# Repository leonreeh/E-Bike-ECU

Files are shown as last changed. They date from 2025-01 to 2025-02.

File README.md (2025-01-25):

# E-Bike ECU

This repository contains the firmware and hardware design files for an Electronic Control Unit (ECU) tailored for E-Bikes. Developed as part of a technical project, it encompasses various components essential for the efficient operation and control of electric bicycles.

## Project Overview

The E-Bike ECU project aims to provide a comprehensive solution for managing and controlling the functionalities of an electric bicycle. The project includes:

- **BLDC-ESC-Firmware**: Firmware for the Brushless DC (BLDC) motor Electronic Speed Controller (ESC).
- **Gehäuse STL**: 3D printable STL files for the ECU housing.
- **LCD Case**: 3D printable STL files for the LCD display casing.
- **Motor Test Stand**: 3D printable STL files for a motor testing Setup.
- **RESC_V2 Hardware**: Hardware design files for the revised ESC version 2, Inlucding Bill of materials an Gerber files for PCB manufacturing.

## Features

- **Motor Control**: Control interface for Sensored BLDC motors up to 60V/1000W.
- **Intigrated Lighting Control**: Designed to drive 12V bike or motorcycle LEDs.

## Getting Started

To get started with this project:

1. **Clone the Repository**:
   ```bash
   git clone https://github.com/leonreeh/E-Bike-ECU.git
2. **Explore the Directories**:
Navigate to the BLDC-ESC-Firmware folder for motor control firmware.
Access the Gehäuse STL and LCD Case directories for 3D printable designs.
Refer to the Motor Test Stand folder for test stand setup 3D printable designs.
Review the RESC_V2 Hardware directory for the latest hardware schematic, layout and Bill of Material.

3. **Prerequisites Hardware**:
Sensored BLDC motor and Compatible Battery (12-60V).
3D printer for housing components.
Necessary electronic components as per the hardware design files.

4. **Software**:
STM32CubeIDE 1.16.1 or GNU Make for building the firmware.
Autodesk Fusion 360/Eagle for viewing and editing hardware schematics.
Installation
Firmware Compilation:
Navigate to the BLDC-ESC-Firmware directory.
Upload the compiled firmware to the ESC using ST-Link V2 or your preferred flashing tool.

## Acknowledgments
**Contributing**
Contributions to enhance this project are welcome. Feel free to fork the repository, make improvements, and submit pull requests.

**License**
This project is licensed under the MIT License. See the [wikipedia.org/wiki/MIT-License](https://de.wikipedia.org/wiki/MIT-Lizenz) for details.

This project was inspired and informed by several resources:

1. **VESC-Project**  Hardware reference and inspiration.
2. **Microchip** AN4064 Application Notes: Sensored (Hall Effect Sensor-Based) Field Oriented Control of Three-Phase BLDC Motor Using dsPIC33CK.
3. **Texas Instruments**
   Application Report: Trapezoidal Control of BLDC Motors Using Hall Effect Sensors.
   Demystifying BLDC motor commutation: Trap, Sine, & FOC
4. **Simple-circuits.com** Sensored brushless DC motor control.
5. **Stratify Labs** Motor Control using PWM and PID.
Special thanks to all contributors and the open-source community for their invaluable resources and Guidance.

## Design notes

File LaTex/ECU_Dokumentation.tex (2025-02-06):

\documentclass[paper=a4,11pt]{scrreprt}

\usepackage[utf8]{inputenc}
\usepackage[ngerman]{babel}
\usepackage[T1]{fontenc}	
\usepackage{amsmath}
\usepackage{graphicx}
\usepackage{listings}
\usepackage{pdfpages}

\renewcommand\lstlistingname{Source Code}
\renewcommand\lstlistlistingname{Source Code}

\usepackage{xcolor}
\definecolor{codegreen}{rgb}{0,0.6,0}
\definecolor{codegray}{rgb}{0.5,0.5,0.5}
\definecolor{codeorange}{rgb}{1,0.49,0}
\definecolor{backcolour}{rgb}{0.95,0.95,0.96}
\definecolor{funccolour}{rgb}{0.3, 0.6, 0.9}

\lstdefinestyle{mystyle}{
    backgroundcolor=\color{backcolour},   
    commentstyle=\color{codegray},
    keywordstyle=\color{codeorange},
    numberstyle=\tiny\color{codegray},
    stringstyle=\color{codegreen},
    identifierstyle =\color{funccolour},
    basicstyle=\ttfamily\footnotesize,
    breakatwhitespace=false,         
    breaklines=true,                 
    captionpos=b,                    
    keepspaces=true,                 
    numbers=left,                    
    numbersep=5pt,                  
    showspaces=false,                
    showstringspaces=false,
    showtabs=false,                  
    tabsize=2,
    xleftmargin=10pt,
}
\lstset{style=mystyle}

\title{Technikerprojekt: E-Bike ECU}
\author{Leon Reeh}
\date{\today}

\begin{document}

\maketitle
\paragraph{Vorwort}
Um das Lesen zu vereinfachen, wurde die Dokumentation in vier Teile unterteilt. Diese vier Abschnitte beschäftigen sich jeweils vollständig mit einem Aspekt des Projekts und stehen für sich:\\
\textbf{Teil 1}: Einleitung und Beschreibung des vollständigen Systems.\\ 
\textbf{Teil 2}: Dokumentation des fertigen Schaltplans, Layouts, der Software und Mechanik im Detail. \\
\textbf{Teil 3}: Der Entwicklungsprozess mit Designänderungen und deren Hintergründen.\\ 
\textbf{Teil 4}: Anhänge, einschließlich des vollständigen Schaltplans und Quellausschnitte.\\
\\Die vollständige Dokumentation sowie der vollständige und durchgehend verfügbare Software-Quellcode, Schaltpläne und weitere Dateien stehen ebenfalls in digitaler Form auf GitHub unter \textbf{https://github.com/leonreeh/E-Bike-ECU} zur Verfügung.
\paragraph{Lizenz}
Dieses Projekt und die hier beiliegende dokumentation fallen unter die MIT-Lizenz (X11-Lizenz) \emph{Leon Reeh 2025} 

\tableofcontents
\newpage

\part{Einleitung und Projektbeschreibung}
\chapter{Einleitung}
\textbf{Ziel des Projekts} ist die Entwicklung eines Steuergeräts für einen akkubetriebenen BLDC-Heckmotor mit einer Nennleistung von 1000 W bei 48 V für ein E-Bike. Das Steuergerät soll alle relevanten Bedienelemente für den Motorbetrieb sowie die Steuerung der Beleuchtung integrieren. Die Umsetzung erfolgt mit einer selbst entwickelten Platine auf Mikrocontroller-Basis und einer eigens programmierten Software.
\textbf{Motivation}
Warum habe ich dieses Projekt gewählt? 
Nach zehn Jahren Firmenzugehörigkeit bei Panasonic Lüneburg – einem Unternehmen mit Fokus auf dedizierte Elektroniklösungen – war für mich klar, dass die Entwicklung einer eigenen Elektronik im Mittelpunkt meines Techniker Projekts stehen sollte. Elektrische Antriebe sind nach wie vor ein aktuelles Thema, weshalb die Idee eines E-Bike-Antriebs nahe lag.
Warum 1kW als Herausforderung?
Mit großer Leistung kommt große Verantwortung! Da ich das Projekt privat und unter selbst gestellten Anforderungen entwickeln wollte, setzte ich bewusst auf eine hohe Leistung von 1 kW. Bei Strömen über 20 A ist die Fehlertoleranz gering. Die Bauteile müssen sorgfältig ausgewählt werden, Leiterbahnen und Kabelquerschnitte müssen korrekt dimensioniert sein, und Sicherheits- sowie Abschaltfunktionen müssen sowohl in Hardware als auch in Software sicher implementiert werden, um die Funktion und den Personenschutz zu gewährleisten.
\section{Technische Spezifikation}
\textbf{E-Bike}:\\
Reichweite: 20-40km abhängig von Fahrweise\\
Höchstgeschwindigkeit: >40km/h\\
Leistung/Ps: ~1KW/1,36PS\\
\textbf{Akku}:\\
Ausgangsspannung: 56V-43V\\
Ausgangsstrom: 30A\\
Energie: 15A/h\\
\textbf{Steuergerät}:\\
Eingangsspannung: 13V-64V\\
Stromaufnahme: standby 0.10A/ max 22 A \\
Leistungsaufnahme: 1,3W - 1.218W\\
Temperaturbereich Umgebung(Tu): 10°C - 40°C\\
Temperaturbereich Elektronik: Tu - 120°C\\

\chapter{Systemdesign}

Das fertige System besteht aus sechs Baugruppen, die über das eigens entwickelte Steuergerät vereint werden (siehe Anhang System Design \ref{EBike_sys}). Dadurch entsteht ein vollständig integriertes System, das dem Nutzer die Bedienung des E-Bikes erleichtert.
\textbf{Akku}: 48 V, 15 Ah Lithium-Ionen-Batterie
\textbf{Motor}: Viribus 26-Zoll BLDC-Heckmotor mit 1000 W Nennleistung
\textbf{Display}: 20x4 LCD-Display zur Anzeige von Geschwindigkeit und Systeminformationen
\textbf{Bedienelemente}: „Motorrad-Style“-Lenkerbedienung für alle Funktionen
\textbf{Beleuchtung}: Abblendlicht, Rücklicht, Bremslicht und Blinker
\textbf{Steuergerät}: Das Fokus Element der Techniker Arbeit.\\ Siehe Anhang System Design \ref{SysKomp} für eine Übersicht der relevanten System Bauteile.

\section{Funktionsbeschreibung}

\begin{figure}[ht]
\begin{center}
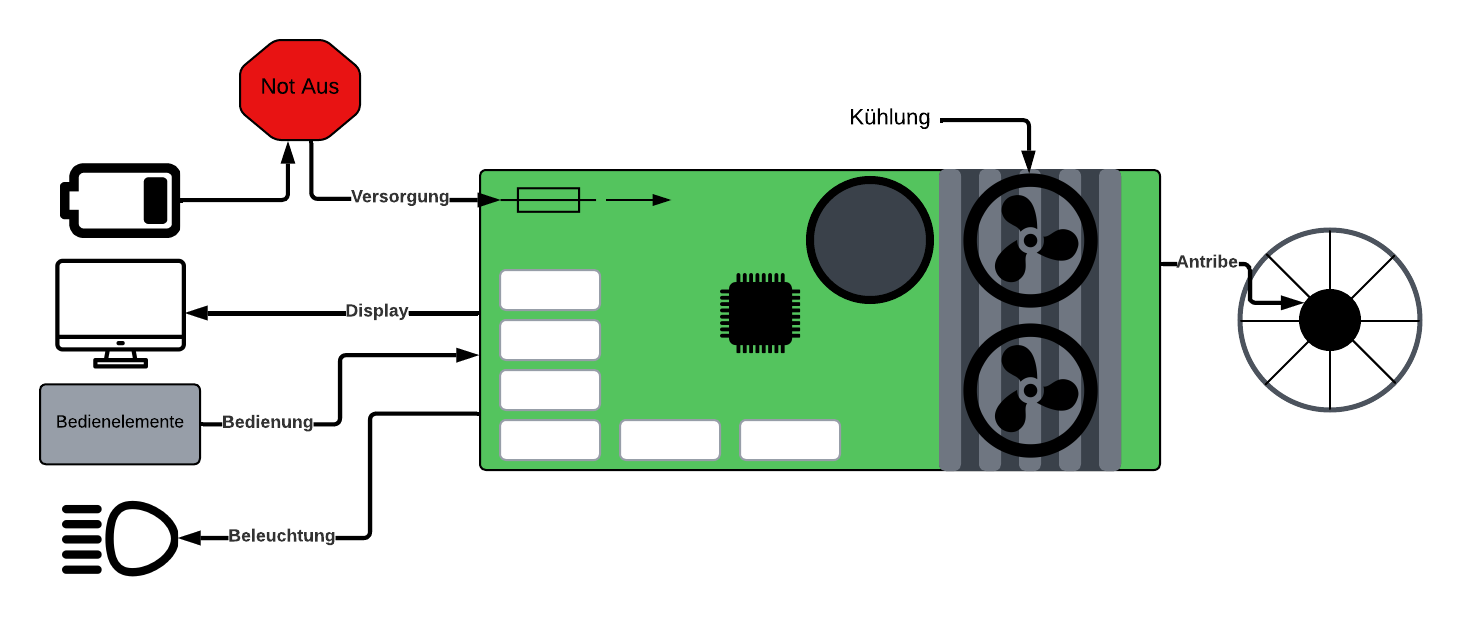
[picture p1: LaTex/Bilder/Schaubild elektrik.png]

\caption{Vereinfachtes Steuergerät}
\label{ECU_sys}
\end{center}
\end{figure}

Das Steuergerät des E-Bikes bietet folgende Hauptfunktionen:
BLDC-Heckmotor-Antrieb: 3-Phasen H brücke für den Antriebe eines bürstenlosen Gleichstrommotor (Brushless DC/BLDC).
Beleuchtungselemente:
Integrierte LED-Vorder- und Rücklichter sorgen für Sichtbarkeit und Sicherheit.
Blinkerelemente und Bremslicht für Richtungsanzeigen.
Darstellung wichtiger Betriebsdaten über LCD:
Spannung, Strom, Temperatur,Geschwindigkeit,Fehler Code.
Integrierte Temperatur-Überwachung mit diskreter Lüfter Ansteuerung.

\section{Bedienung}

\begin{figure}[ht]
\begin{center}
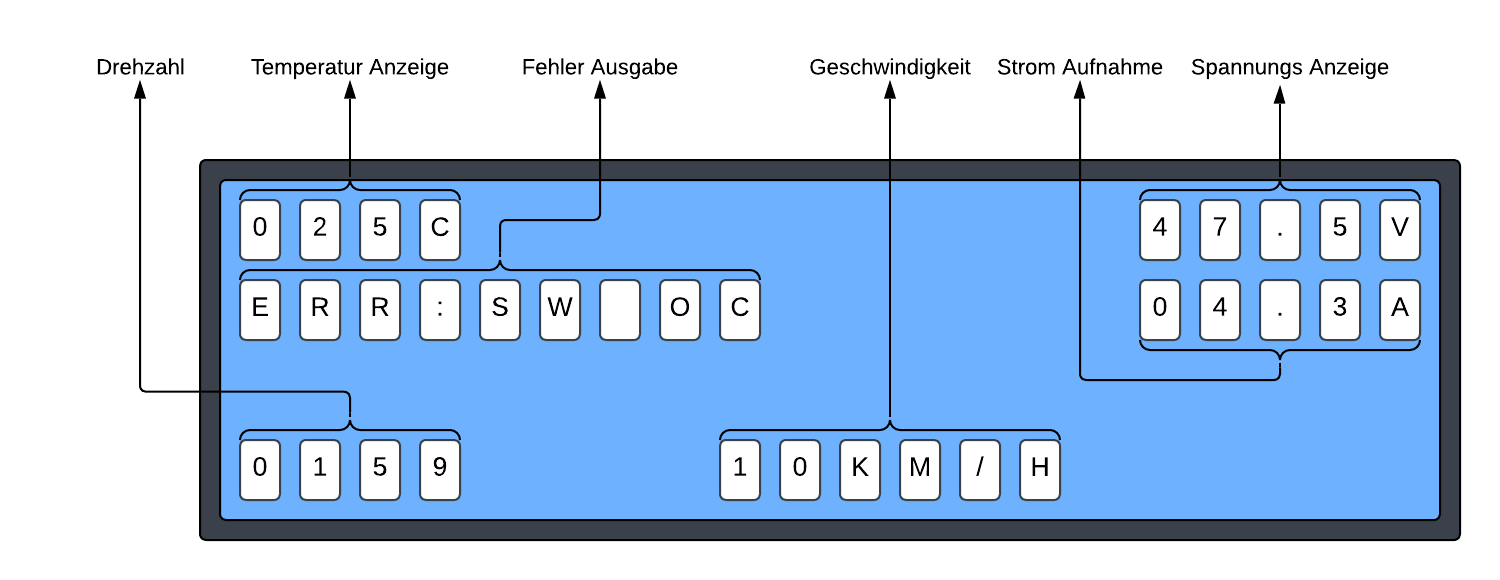
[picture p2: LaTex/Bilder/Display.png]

\caption{Display Ausgabe}
\label{display}
\end{center}
\end{figure}

Die verschiedene Bedienelemte für den Benutzer befinden sich am Lenker in einem Motorrad ähnlichem system:
\textbf{E-Stop}: Deaktiviert das Selbsthalte-Relais und schaltet das Steuergerät aus.
\textbf{E-Start}: Aktiviert das Gerät und betätigt das Selbsthaltesystem, wodurch das E-Bike in den Betriebsmodus versetzt wird.
\textbf{Bremshebel}:
Aktiviert die Bremslichter.
Schaltet die Motorbremse am Hinterrad ein, um eine zusätzliche Verzögerung zu bieten.
\textbf{Gasgriff}: Reguliert die Motorleistung und steuert die Geschwindigkeit.
\textbf{Beleuchtung}:
\textbf{Taster Ablendlicht}: Schaltet das Ablendlicht und den Rückstrahler ein.
\textbf{Taster Blinker Links/Blinker Rechts}: Steuert die Blinkerelemente für die jeweilige Fahrtrichtung.
Diese Funktionen und Eingabemöglichkeiten stellen sicher, dass das E-Bike sowohl sicher als auch benutzerfreundlich im Betrieb ist.\\

\newpage
\section{Sicherheitsfunktionen}

\begin{figure}[ht]
\begin{center}
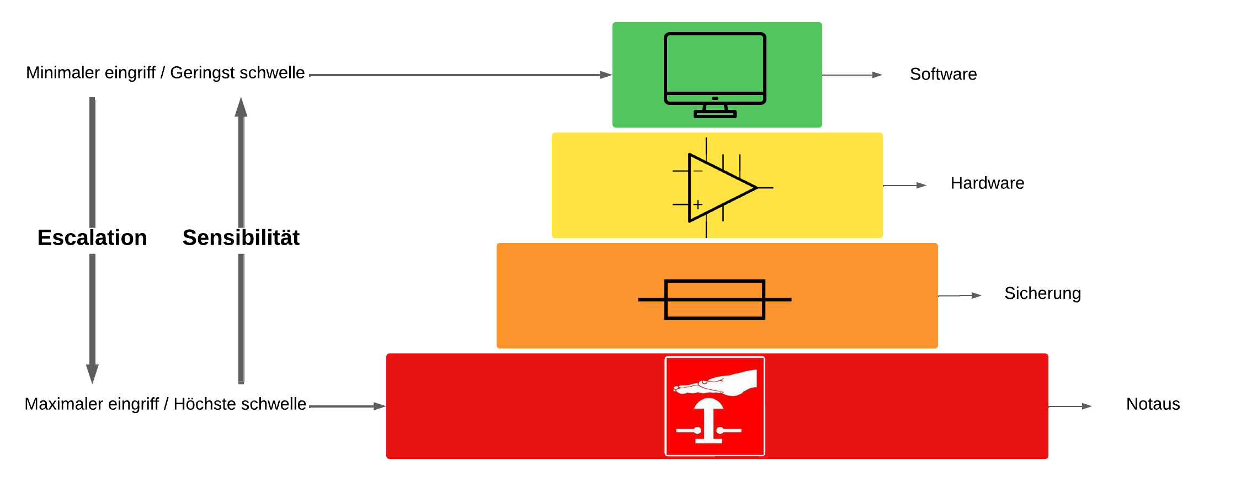
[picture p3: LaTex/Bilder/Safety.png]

\caption{Sicherheitsfunktion}
\label{safety}
\end{center}
\end{figure}

\textbf{1 Software}\\
Auslösung: Messvorrichtungen überwachen Spannung, Strom und Temperatur. Überschreiten diese Werte festgelegte Schwellen, wird der Lastbetrieb automatisch abgeschaltet.
Eingriff: Das Gerät wechselt in einen Sicherheitszustand, aus dem es sich selbstständig zurücksetzen kann, sobald die Bedingungen wieder im Normalbereich liegen.\\
\textbf{2 Hardware}\\
Auslösung: Hardwarebasierte Messvorrichtungen erkennen Spannungen, Ströme oder Temperaturen außerhalb der spezifizierten Werte und schalten das Gerät ab.
Eingriff: Das Gerät wechselt in einen Sicherheitszustand, der nur durch einen manuellen Neustart wieder verlassen werden kann.\\
\textbf{3 Sicherung}\\
Auslösung: Stromkreise für 48V (25A) und 12V (3A) sind durch Sicherungen gegen Kurzschlüsse geschützt.
Eingriff: Bei Überlast oder Kurzschluss wird das Gerät außer Betrieb gesetzt. Zum Wiederinbetriebnehmen müssen die betroffenen Stecksicherungen ersetzt werden.\\
\textbf{4 Notaus}\\
Auslösung: Im Notfall betätigt der Nutzer den Notaus-Schalter.
Eingriff: Das Gerät wird sofort vom Akku getrennt und vollständig stromlos gemacht, um maximale Sicherheit zu gewährleisten.\\
\textbf{Hinweis zu BMS-Schutzfunktionen}\\
Das im Akku integrierte Battery Management System (BMS) verfügt zusätzlich über Schutzvorrichtungen gegen Überstrom, Unterspannung und Überhitzung. Diese Funktionen sind unabhängig von den hier beschriebenen Sicherheitsmaßnahmen und waren nicht Teil der Projektarbeit. Dennoch tragen sie wesentlich zur Gesamtsicherheit des Systems bei.

\part{Schaltplan, Layout und Software}
\chapter{Schaltplan}
In diesem Abschnitt der Dokumentation werden die einzelnen Teile des Schaltplans vorgestellt und detailliert beschrieben. Der vollständige, ununterbrochene Schaltplan ist Im Anhang oder Digital auf GitHub unter: github.com/leonreeh/E-Bike-ECU $\rightarrow$ RESC\_V2 Hardware $\rightarrow$ RESC\_V2 Schematic.pdf\\
Zur besseren Übersicht und Verständlichkeit des Schaltplans wird die folgende Namensgebung für Signale verwendet:\\
\textbf{SENSE} – Signal eines analogen Ausgangs (z. B. Spannungsmessung).\\
\textbf{DI} – Digitaler Eingang (Digital-Logik-Eingang des Mikrocontrollers).\\
\textbf{DO} – Digitaler Ausgang (Digital-Logik-Ausgang des Mikrocontrollers).\\
\textbf{¯¯¯} – Invertierung (Signal arbeitet als Active Low – ausgelöst bei Pegel 0).

\subsection{Kernbauteile}

\begin{tabular}[h]{l|c|r}
\textbf{Bauteil} & \textbf{Name} & \textbf{Beschreibung} \\
\hline
Mikrocontroller & STM32F405RGT6 & 32bit ARM 1024 FLASH 192kB SRAM \\
\hline
Abwärtswandler & LMR36520 & 2,5A DC/DC Converter 4-65V\\
\hline
Brücken Treiber & IR2101S & Bootstrap Brückentreiber\\
\hline
Power Mosfet & IPB035N08N3GATMA & 80V/100A NMos\\  
\hline
Leistungs Relais & JD2912-1Z-12VDC & 12V/40A DC\\
 \hline
Akkustecker & XT90 & 500V/40A DC\\
\hline
Motorstecker & MT60 & 500V/30A DC\\
\hline
Systemstecker & JST-XH Serie & 250V/3A DC\\
\hline
\end{tabular}

\section{Netzteil}
Das Netzteil bildet das Herzstück der Energieversorgung und stellt sicher, dass alle elektronischen Komponenten des Systems mit den benötigten Spannungen und Strömen versorgt werden. Es gewährleistet einen stabilen Betrieb der Elektronik.
\textbf{Funktionalität:}\\
Selbsthalterelais für zuverlässiges Einschalten, für zusätzlichen Schutz gegen Vibrationen und erschüttern wurde hier ein KFZ Relais gewählt das eine besseres Haltemoment als herkömmliche printrelais bietet. \\
48V Hochleistungsversorgung für den Motor\\
DC/DC-Wandler (12V) für Beleuchtung und leistungs Elemente (max. 2.5A)\\
DC/DC-Wandler (5V) für Display und logik Elemente (max. 2A)\\
LDO-Regler (3.3V) für eine besonders stabile Versorgung auf Logik-Ebene.\\
\textbf{Besonderheiten:}
Messung des Eingangsstroms
Messung der Eingangsspannung
Hardwarebasierte Überstromerkennung
Hardwarebasierte Unterspannungserkennung.
\newpage

\subsection{Powertrain}

\begin{figure}[ht]
\begin{center}
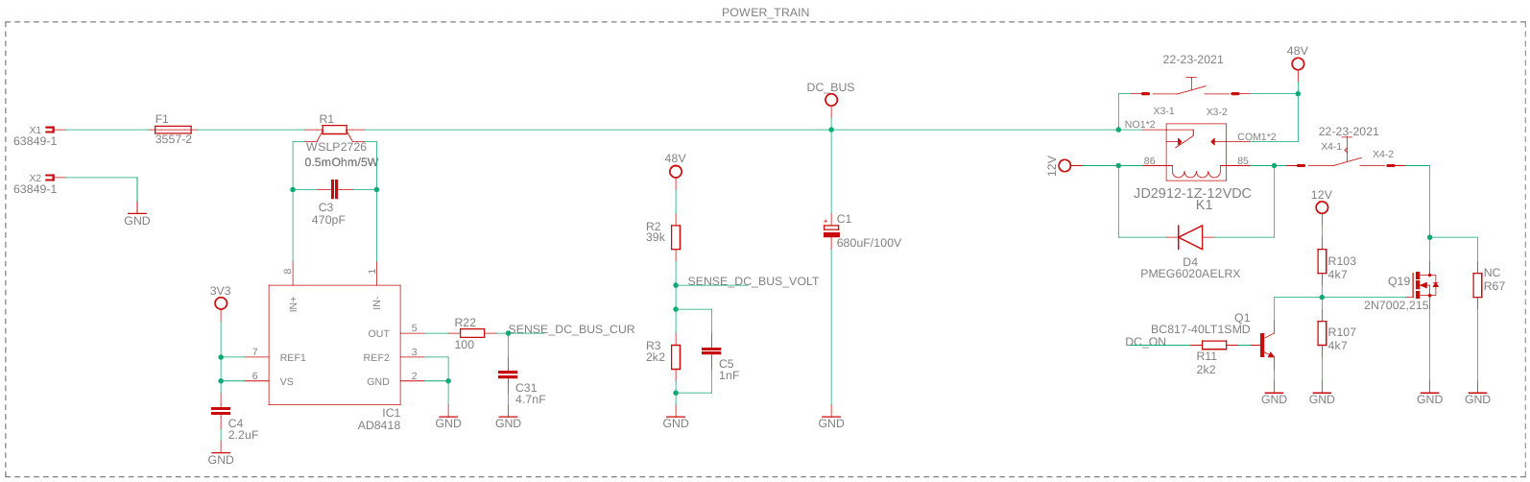
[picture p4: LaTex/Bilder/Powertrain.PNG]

\caption{RESC\_V2 Schaltplan Seite 2}
\label{Powertrain}
\end{center}
\end{figure}

In der ersten Funktionsgruppe, dem „Power Train“, sind alle Komponenten zusammengefasst, die in direkter Verbindung mit dem Akku stehen und den Hochleistungspfad für den Motortreiber bilden.
KFZ-Stecksicherung F1: Schützt den Akku vor Überstrom und Kurzschlüssen.
Shunt R1: Misst den Eingangsstrom und ermöglicht eine präzise Erfassung des Stromverbrauchs.
Spannungsteiler R2/R3: Dient zur Messung der Eingangsspannung und leitet die Daten an die Steuerung weiter.
Bulk-Kondensator C1: Glättet Spannungsspitzen und stabilisiert die Eingangsspannung, um Schwankungen auszugleichen.
Selbsthalte-KFZ-Relais K1: Schaltet die versorgungsspannung des Niederleistungspfad und sorgt dafür, dass das System sicher ein und ausgeschaltet werden kann.
Diese Funktionsgruppe ist essenziell für die sichere Versorgung des Motortreibers und bildet die Grundlage für die gesamte Energieversorgung des E-Bikes.

\subsection{DC/DC}

Um unnötige Verlustleistung zu vermeiden und die Komplexität des Netzteils gering zu halten, werden für die Versorgung der Elektronik lediglich drei Spannungsebenen benötigt:\\
\textbf{12V} – System-Leistungsspannung als Versorgung der Beleuchtung, Lüfter, Relais und des Motortreibers.\\
\textbf{5V} – Sensor- und Displayversorgung für Motor-Hall-Sensoren und des LCD-Displays.\\
\textbf{3.3V} – System-Logikspannung für die Versorgung des Mikrocontrollers, Operationsverstärkers und der analogen Signale.\\
Durch die Reduzierung auf diese drei Spannungspegel wird der Aufbau des Netzteils vereinfacht, während gleichzeitig eine stabile und effiziente Energieversorgung für die verschiedenen Baugruppen gewährleistet wird.\\
\newpage

\begin{figure}[ht]
\begin{center}
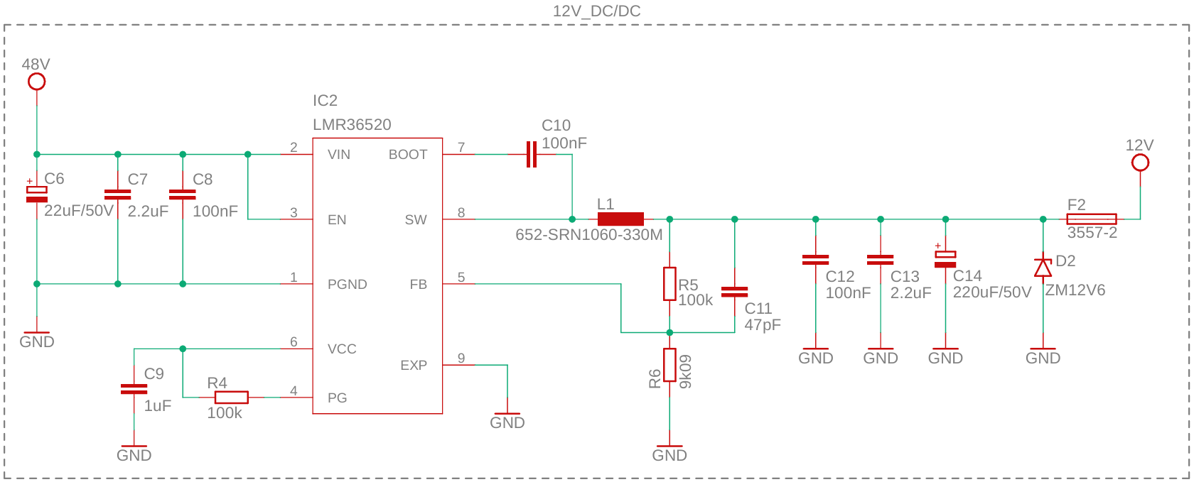
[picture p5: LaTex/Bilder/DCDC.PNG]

\caption{12V Abwärtswandler RESC\_V2 Schaltplan Seite 2}
\label{DCDC}
\end{center}
\end{figure}

Die Beschaltung des LMR36520 entspricht dem TI-Referenzdesign (Datenblatt Abschnitt 9.2 Typical Application) und wurde um eine 12V6 Suppressordiode (Z-Diode) ergänzt, um das System vor Überspannung zu schützen. Diese zusätzliche Schutzmaßnahme trägt zur Erhöhung der Zuverlässigkeit und Langlebigkeit der Spannungsversorgung bei, indem sie Spannungsspitzen effektiv absorbiert und so empfindliche Schaltungsteile schützt
Die Induktivität L1 wurde gemäß den Richtlinien im Datenblatt des LMR36520 dimensioniert (Datenblatt Abschnitt 9.2.1.2.3 – Inductor Selection).

\subsection{Protection circuits}

\begin{figure}[ht]
\begin{center}
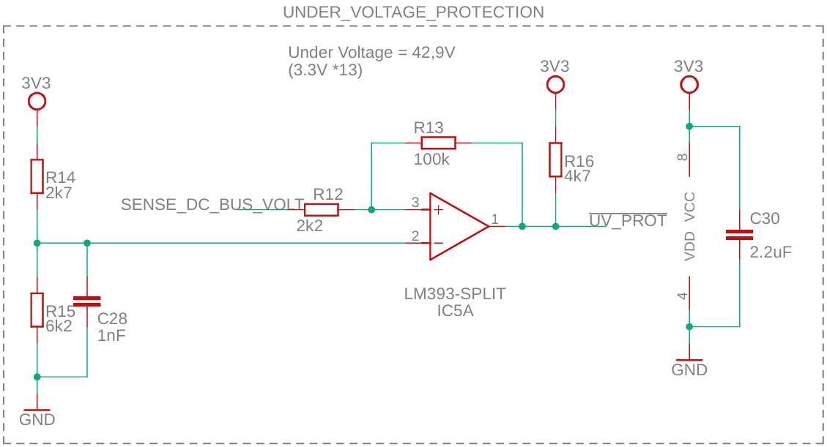
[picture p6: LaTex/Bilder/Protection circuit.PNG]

\caption{Unterspannungsschutz RESC\_V2 Schaltplan Seite 2}
\label{UV}
\end{center}
\end{figure}

Für die Umsetzung der Sicherheitsfunktion auf Hardware-Ebene wurde eine einfache Komparatorschaltung implementiert, die die drei Messgrößen (Spannung, Strom, Temperatur) überwacht. Beim Überschreiten vordefinierter Schwellenwerte sendet sie ein „Fehler“-Signal an den Mikrocontroller.
Im Beispiel in Abbildung \ref{UV} wurde zum Schutz vor Tiefentladung des Akkus eine Spannung von 42,9 V festgelegt. Bei 13 in Reihe geschalteten Zellen ergibt sich daraus eine minimale Zellenspannung von 3,3 V.
Über-Strom und -Temperatur Erkennung werden mit der gleichen Schaltung implementiert und nach relevanten Kriterien dimensioniert.

\subsection{Hardware Interrupt}

\begin{figure}[ht]
\begin{center}
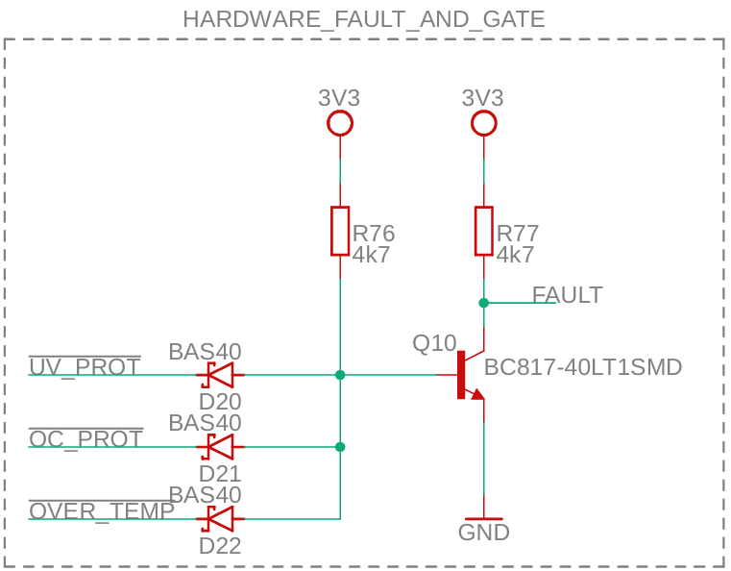
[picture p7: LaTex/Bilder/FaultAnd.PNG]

\caption{Oder Gatter RESC\_V2 Schaltplan Seite 3}
\label{orGate}
\end{center}
\end{figure}

Um sicherzustellen, dass die Elektronik im Falle eines Hardware-Fehlers immer konsistent reagiert, werden die drei Hardware-Fehlersignale (Strom, Spannung, Temperatur) über ein ODER-Gatter zusammengefasst.
Das resultierende \textbf{"FAULT"}-Signal wird auf einen Interrupt-Pin des Mikrocontrollers gelegt, sodass dieser bei einem Fehler schnellstmöglich reagieren kann. Durch diese einfache Hardwareschaltung können zwei zusätzliche Interrupt-Pins eingespart werden, da alle drei Fehlersignale zum selben Sicherheitszustand führen sollen und daher keinen eigenen Interrupt-Pin benötigen.

\subsection{Mikrocontroller}
Der STM32F405RGT6 bildet das zentrale Steuerungselement des Systems und koordiniert die gesamte Elektronik. Er übernimmt die Verarbeitung und Weiterleitung von Signalen, die Überwachung der Systemparameter, die Kommunikation mit anderen Modulen und nicht zuletzt die Ansteuerung der Motor H-Brücke.

\begin{figure}[ht]
\begin{center}
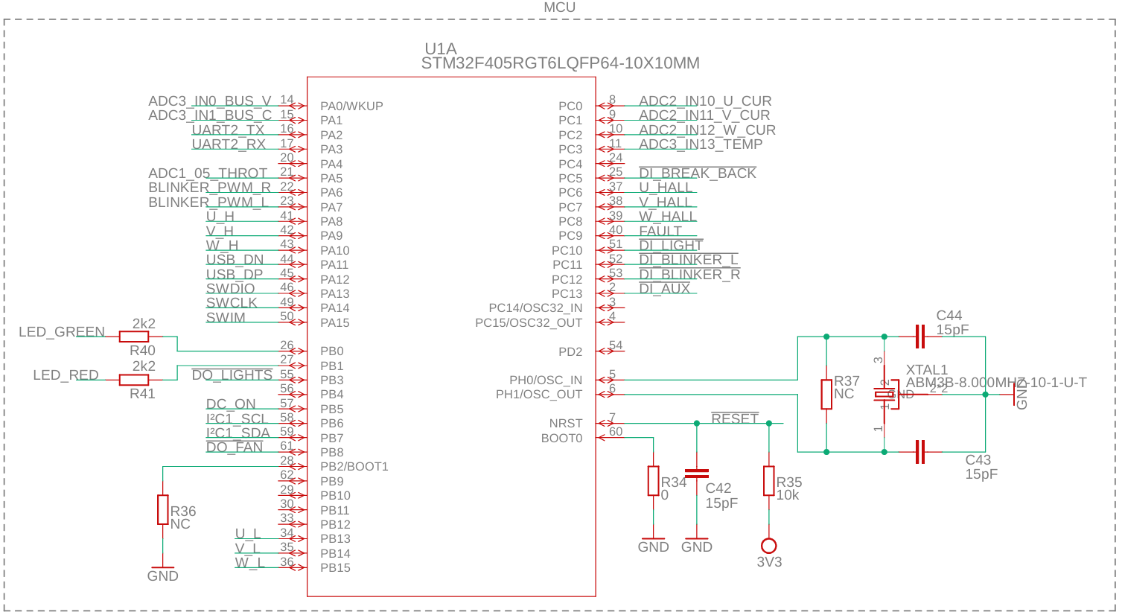
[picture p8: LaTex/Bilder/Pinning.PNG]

\caption{Mikrocontroller Pinbelegung RESC\_V2 Schaltplan Seite 3}
\label{mcu}
\end{center}
\end{figure}

Die Pin-Belegung des Mikrocontrollers wurde mit hilfe des STM32CubeIDE-Konfigurators festgelegt. Dabei wurden die Timer-PWM-Kanäle, Interrupt-Pins und ADCs konfiguriert.
Als Referenz diente der \textbf{VESC 6.4 Schaltplan}, der maßgeblich zur Auswahl des Mikrocontrollers beitrug. Diese Vorgehensweise ermöglichte die Funktions-kritisch Aspekte der notwendigen Peripheriefunktionen für die Motorsteuerung und Systemüberwachung zu implementieren.

\begin{figure}[ht]
\begin{center}
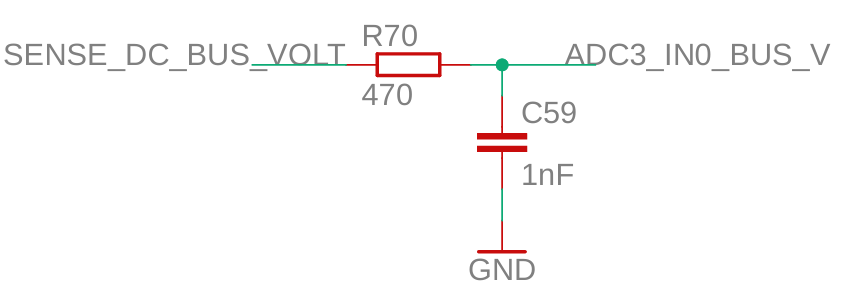
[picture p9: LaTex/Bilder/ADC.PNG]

\caption{RC-Filter RESC\_V2 Schaltplan Seite 3}
\label{ADC}
\end{center}
\end{figure}

Zur Entstörung der Analogsignale sind alle ADC-Pins des Mikrocontrollers mit einem RC-Glied ausgestattet.
Das RC-Glied dient dazu, hochfrequente Störungen zu filtern und sicherzustellen, dass die an den ADC-Eingängen gemessenen Werte stabil und präzise sind. Dies trägt zur Verbesserung der Signalqualität und zur Reduzierung von Messfehlern bei.
\newpage

\begin{figure}[ht]
\begin{center}
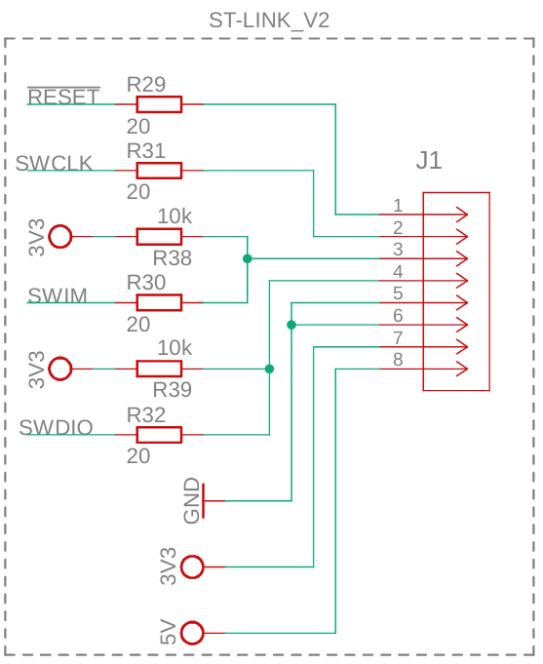
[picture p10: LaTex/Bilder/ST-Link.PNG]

\caption{ST-Link RESC\_V2 Schaltplan Seite 3}
\label{ST_LINK}
\end{center}
\end{figure}

Standard SWD-Schnittstelle zum Programmieren und Debugging von STM-Mikrocontrollern. Die Schnittstelle ist vollständig kompatibel mit dem ST-Link V2 über das Serial Wire Debug (SWD)-Protokoll.

\begin{figure}[ht]
\begin{center}
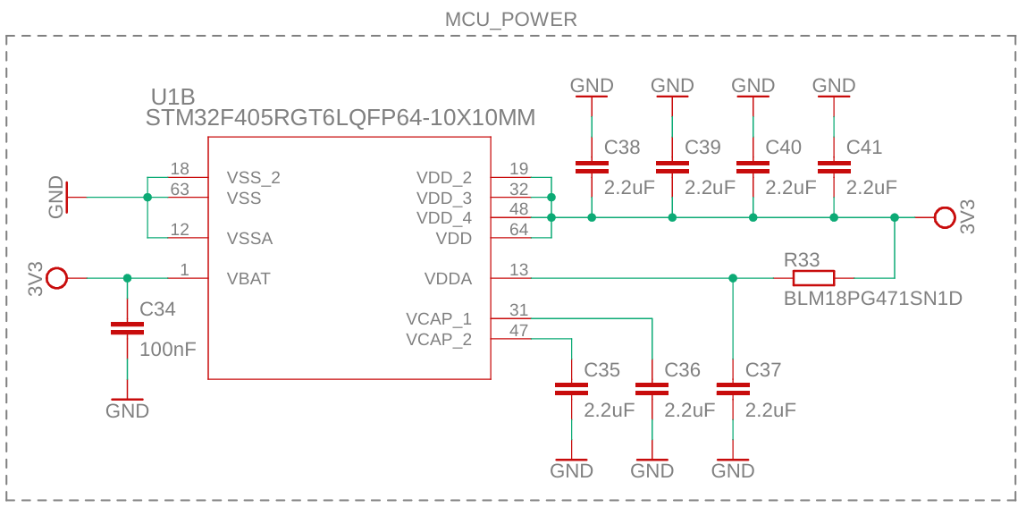
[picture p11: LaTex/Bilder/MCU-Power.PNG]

\caption{Mikrocontroller Versorgung RESC\_V2 Schaltplan Seite 3}
\label{mcu_psu}
\end{center}
\end{figure}

Jeder Versorgungspin des Mikrocontrollers ist mit einem eigenen 2,2 µF Kondensator ausgestattet, um eine möglichst stabile Spannungsversorgung zu gewährleisten. Der ADC-Referenzpin (VDDA) ist zusätzlich mit einem Ferritfilter gegen Störungen geschützt.
\newpage
\subsection{BLDC}
Für die Implementierung des BDLCs wird eine drei Phasen H-Brücke benötigt. dies wurde durch den \textbf{Infineon 2101S} Bootstrap-H-Brücken-Treiber und leistungsstarke \textbf{IPB035N08N3GATMA}-Power-MOSFETs realisiert.

\begin{figure}[ht]
\begin{center}
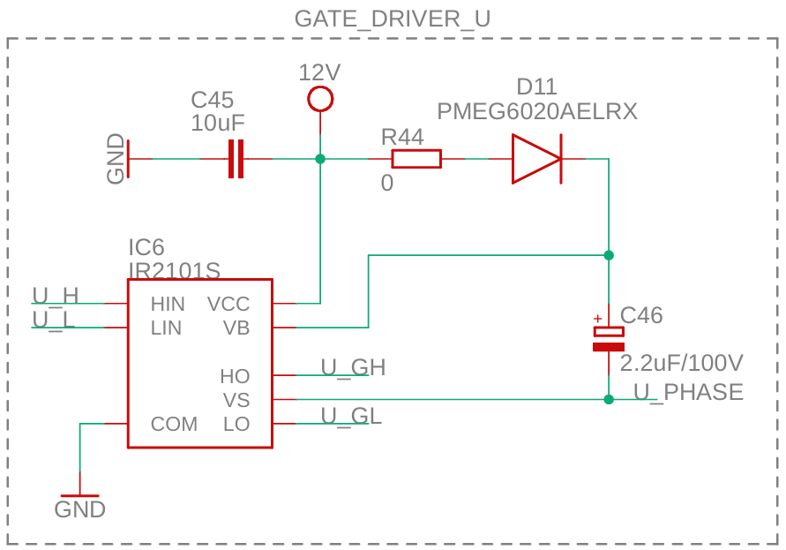
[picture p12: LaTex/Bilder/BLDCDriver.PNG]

\caption{H-Brücken Treibe RESC\_V2 Schaltplan Seite 4}
\label{GateDriver}
\end{center}
\end{figure}

Das Infineon 2101S Treiber IC wurde gewählt für seine einfache Implementierung, Ansteuerung, integrierte Bootstrap-Schaltung und Short Protection. Die Referenzschaltung wurde um einen Vorwiderstand R44 erweitert der es ermöglicht den Ladestrom von C46 zu dimensionieren. \\
Dimensionierung des Bootstrap-Kondensators C46 gemäß der Faustregel:\\ $C_{bootstrap}\geq10\times C_{gs}$ ($C_{gs}$ = 2.2nF Gate-Kapazität der MOSFETs)
Diese Dimensionierung stellt sicher, dass der Treiber auch bei hohen Schaltfrequenzen zuverlässig arbeitet und eine stabile Gate-Spannung bereitgestellt wird.
\newpage

\begin{figure}[ht]
\begin{center}
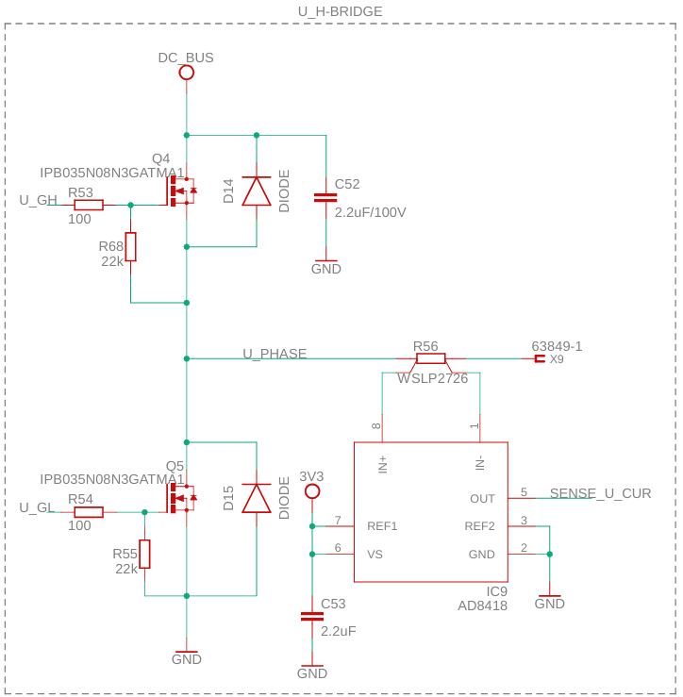
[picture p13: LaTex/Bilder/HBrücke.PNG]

\caption{H-Brück RESC\_V2 Schaltplan Seite 4}
\label{HBridge}
\end{center}
\end{figure}

Die Strom- und Drehmomentregelung erfolgt durch eine Shunt-Messung direkt am Phasenabgriff der H-Brücke, wodurch der tatsächliche Phasenstrom präzise erfasst und eine genauere Motorregelung ermöglicht wird. Zur Entlastung der MOSFET-internen Body-Dioden und zur Reduzierung der thermischen Belastung, insbesondere bei schnellen Schaltvorgängen und hohen Strömen, werden externe Freilaufdioden (D16/D17) parallel zu den MOSFETs geschaltet. Jedes MOSFET ist mit einem Pull-Down-Widerstand am Gate versehen, um ungewolltes Einschalten durch Leckströme zu verhindern und einen sicheren Sperrzustand zu gewährleisten. Zusätzlich ist jede H-Brücke mit einem 2,2 µF Kondensator ausgestattet, der Schalt- und Spannungsspitzen reduziert, die MOSFETs vor Überspannungen schützt und zur Glättung der Phasenspannung beiträgt.
\newpage
\subsection{Beleuchtung}
Die Beleuchtungseinheit steuert die LED-Beleuchtungselemente mittels diskreter MOSFET-Treibern. Ihr primärer Zweck ist die Gewährleistung der gesetzlich vorgeschriebenen sowie funktionalen Fahrzeugbeleuchtung für den Straßenverkehr, wodurch Sicherheit und Sichtbarkeit erhöht werden. Die Beleuchtung umfasst Abblendlicht, Rücklicht, Bremslicht und Blinker, wobei letztere durch Software-PWM geregelt werden, um eine flexible Lichtsteuerung zu ermöglichen.

\begin{figure}[ht]
\begin{center}
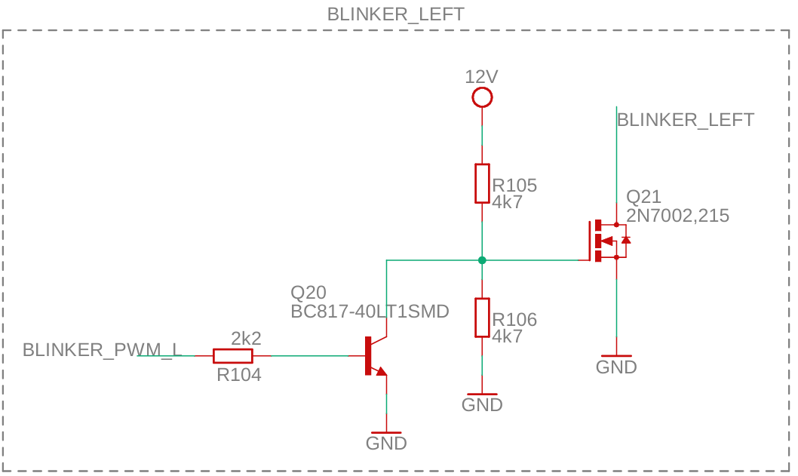
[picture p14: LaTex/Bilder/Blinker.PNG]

\caption{H-Brücken Treibe RESC\_V2 Schaltplan Seite 5}
\label{blinker}
\end{center}
\end{figure}

Alle Beleuchtungs-LEDs verwenden die gleiche Treiberbeschaltung. Der einzige Unterschied zwischen den Treibern liegt in der Größe der MOSFETs, die entsprechend der Leistungsaufnahme der jeweiligen LED-Gruppen dimensioniert werden.
\newpage
\subsection{Temperatur}
Die Temperaturüberwachung dient dem Schutz der Leistungskomponenten durch eine Messung und  Steuerung der Kühlung. Ein NTC-Sensor am Kühlkörper erfasst die Temperatur, während eine MOSFET-basierte Lüftersteuerung, mit optionalem PWM-Betrieb, eine bedarfsgerechte Kühlung ermöglicht. Eine OP-basierte Hardware-Schaltung erkennt Übertemperaturen und reagiert entsprechend, um Schäden an den Leistungskomponenten zu verhindern.
\\

\begin{figure}[ht]
\begin{center}
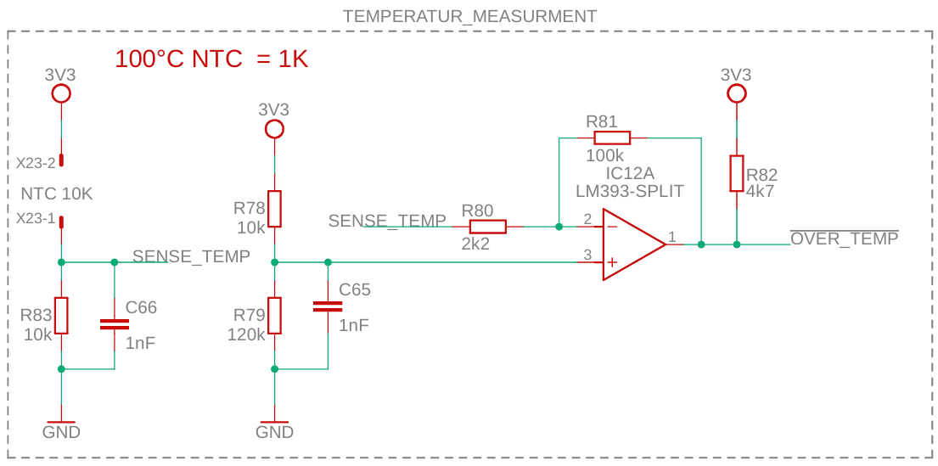
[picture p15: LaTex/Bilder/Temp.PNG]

\caption{Temperaturmessung RESC\_V2 Schaltplan Seite 6}
\label{temp}
\end{center}
\end{figure}

Der \textbf{NTC-Widerstand (R84)} ist direkt am Kühlkörper befestigt, um eine kontinuierliche Überwachung der Systemtemperatur zu gewährleisten. Die Lüftersteuerung erfolgt softwareseitig über eine \textbf{Hysterese}, wobei der Lüfter eingeschaltet wird, sobald die Temperatur \textbf{80°C} übersteigt, und wieder abgeschaltet wird, sobald sie unter \textbf{60°C} fällt. Falls die softwaregesteuerte Regelung nicht ausreicht, um den Temperaturanstieg zu begrenzen, greift eine hardwarebasierte Fehlererkennung bei \textbf{120°C} ein. Diese löst automatisch Schutzmaßnahmen aus, um die MOSFETs vor Überhitzung und möglichen Schäden zu bewahren.\\
Für das Ansteuern von zwei 40mm PC-Lüftern wird ein MOSFET-Treiber verwendet. Die Steuerung der Lüfter erfolgt über den Digital Output DO-FAN, der wahlweise im PWM-Betrieb oder im Digitalbetrieb arbeiten kann.
\newpage
\subsection{IO}
Das Eingabe- und Ausgabe-Modul ermöglicht die Interaktion zwischen Benutzer und System durch die Erfassung von Eingabeelemente wie Taster sowie die Ausgabe von Systeminformationen auf einem Kommunikationsschnittstelle. Die Kommunikationsschnittstelle kann wahlweise über eine I²C- oder UART Daten übertragen, wodurch eine flexible Integration in verschiedene Systemarchitekturen ermöglicht wird wie z.b LDC-Displays oder mehr Fortgeschrittene TFT Touch Tabletts.

\begin{figure}[ht]
\begin{center}
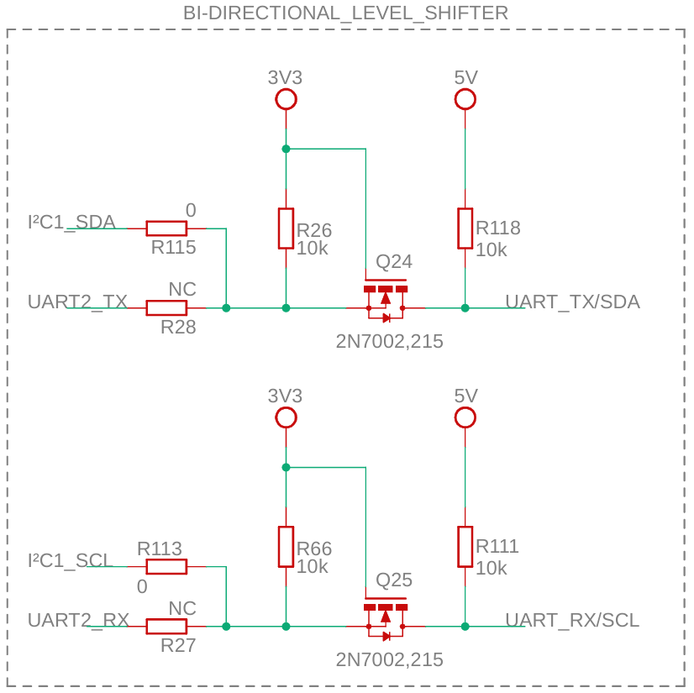
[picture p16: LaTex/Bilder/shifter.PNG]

\caption{Bidirektionaler-Levelshifter RESC\_V2 Schaltplan Seite 7}
\label{shifter}
\end{center}
\end{figure}

Die Konfigurierung der Kommunikationsschnittstelle, erfolgt über das bestücken der entsprechenden Widerstände (R28, R27 oder R115, R113). Diese Anpassungsmöglichkeit ermöglicht die Anbindung einer Vielzahl kompatibler Displays und Peripheriegeräte. Zur Sicherstellung der Kompatibilität mit Arduino-Komponenten, die auf einem 5V-Logiklevel arbeiten, ist die Schnittstelle zusätzlich mit einem Bidirektionalem 3.3V/5V-Level-Shifter ausgestattet. Dieser gewährleistet eine zuverlässige Kommunikation zwischen den Komponenten, unabhängig vom verwendeten Logikpegel.

\chapter{Layout}
In diesem Kapitel wird das Layout der Leiterplatte (PCB) detailliert beschrieben. Ziel ist es, die wichtigsten Designentscheidungen, Regelwerke und Dimensionierungen zu dokumentieren, um die optimale Funktion und Zuverlässigkeit des Systems sicherzustellen. Das angefertigte Layout finden Sie im Anhang oder digital auf: 
github.com/leonreeh/E-Bike-ECU $\Rightarrow$ RESC\_V2 Hardware $\Rightarrow$ RESC\_V2 PCB.pdf

\begin{figure}[ht]
\begin{center}
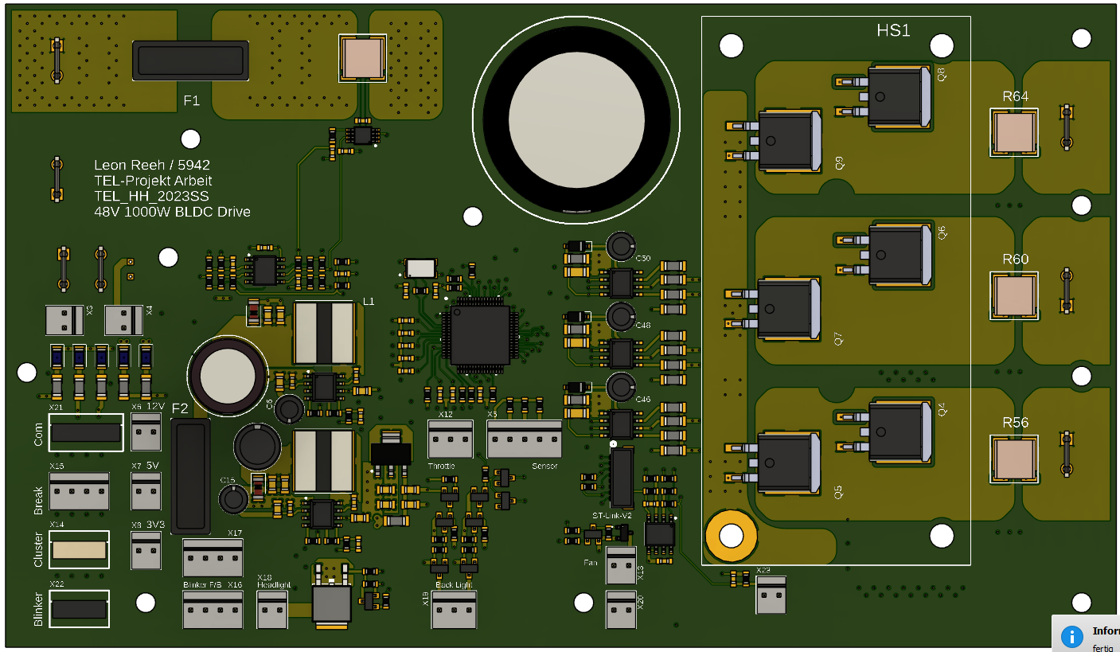
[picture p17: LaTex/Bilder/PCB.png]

\caption{RESC\_V2 Leiterplatte}
\label{pcb}
\end{center}
\end{figure}
\newpage
\section{Design Regeln}
Für die Leiterplattenentwicklung wurden folgende Design-Regeln definiert:
\textbf{Leiterbahnbreiten und -abstände:} Signal-Leitungen werden mit einer Breite von 8 mil ausgeführt, während Versorgungsleitungen im Kleinspannungsbereich ($\geq$ 12 V) 20 mil breit sind. Für Hochleistungspfade beträgt die Mindestbreite 700 mil.
\textbf{Via-Dimensionierung:} Die Vias werden gemäß den Vorgaben des PCB-Herstellers (JLCPCB) dimensioniert und besitzen eine Bohrung von 0,3 mm.
\textbf{Isolationsabstände:} Im Signalbereich beträgt der Isolationsabstand 16 mil (entspricht dem Zweifachen der Signal-Leitungsbreite), im Versorgungsnetz 20 mil und im Hochleistungsbereich 100 mil.
\textbf{Bauteilplatzierung}: Die Bauteile werden entsprechend ihren Schaltplangruppen angeordnet, sodass jede Gruppe ein schlüssiges Layout bildet. Dabei gilt die Regel: Komponenten, die zusammenarbeiten, werden auch physisch zusammen platziert. Beispielsweise werden RC-Filter (Widerstand und Kondensator) direkt nebeneinander und so nah wie möglich am zu filternden Eingang positioniert.
\textbf{Lagenaufteilung:} Der Top Layer (Layer 1) dient als Hauptbestückungslayer, während der Bottom Layer (Layer 6) als Hilfslayer genutzt wird, insbesondere für die Platzierung von Abblock-Kondensatoren nahe an den Versorgungspins des Mikrocontrollers.

\section{PCB Dimensionierung}
Die Platine besitzt eine Abmessung von 190 × 110 mm. Die einzige kritische Vorgabe bezüglich der Außenmaße war, dass sie kleiner als 210 × 210 mm bleibt, damit das PCB-Trägergehäuse auf ein 3D-Druckbett passt.\\
Die Befestigung erfolgt über mehrere M3-Schrauben, die das PCB sicher im Gehäuse fixieren. Besondere Aufmerksamkeit wurde auf die Befestigung großer und schwerer Bauteile gelegt, ebenso wie auf Bereiche, die unter mechanischer Belastung stehen, beispielsweise Stecker und Kabel. Diese Maßnahmen minimieren Biegestress und Vibrationen der Elektronik.\\
Die Design-Toleranzen richten sich nach den Fertigungsvorgaben von JLCPCB:\\
PCB-Outline: ±0,2 mm\\
Pad-Pad-Abstand: 6 mil\\
Pad-Via-Abstand: 6 mil\\
Die Steckerplatzierung wurde so gestaltet, dass eine einfache Handhabung ermöglicht wird. Stecker sind daher möglichst nah am Platinenrand positioniert, wobei die Orientierung der Platine innerhalb des Gehäuses berücksichtigt wurde. Beispielsweise sind:

Stecker für den Motor auf der Rückseite, da sich der Motor hinter der Elektronik befindet.
Stecker für Bedienelemente auf der Vorderseite, da diese leicht zugänglich sein müssen.
Eine Ausnahme bilden der Stecker für den Motor-Hall-Sensor sowie der Stecker für den Analog-Gasgriff. Diese wurden in der Nähe des Mikrocontrollers platziert, um eine optimale Signalanbindung zu gewährleisten.

\section{Layer Design}
Um unerwünschte Störeinflüsse zu minimieren und die Signalqualität zu gewährleisten, wurden die sechs zur Verfügung stehenden Layer in spezifische Signalgruppen aufgeteilt. Dies ermöglicht eine klare Trennung von Leistungs- und Signalleitungen mit dem ziel elektromagnetische Störungen (EMI) zu reduzieren. Die Verteilung der Layer folgt einem logischen Aufbau, der sich an bewährten Industriepraktiken orientiert:\\

\begin{figure}[ht]
\begin{center}
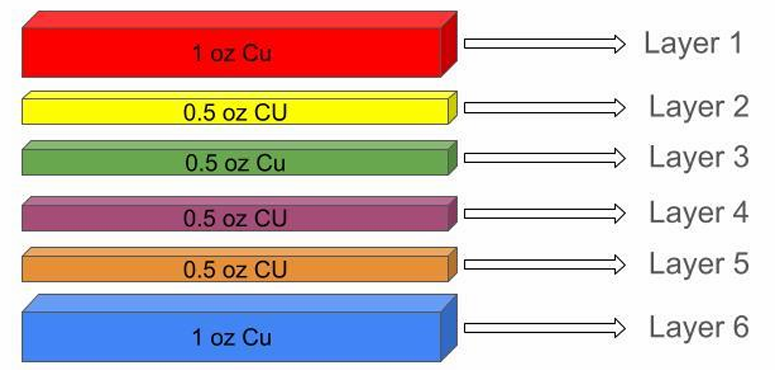
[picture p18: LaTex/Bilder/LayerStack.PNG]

\caption{6-Layer PCB Stackup RESC\_V2 Layout}
\label{lstack}
\end{center}
\end{figure}

Layer:\\
1. Baugruppen- und Power-Layer\\
2. Signal-Ground-Layer\\
3. Primär Digital-Signal-Layer\\
4. Analog-Signal-Layer\\
5. Kleinspannungs-Power-Layer (12V, 5V, 3.3V)\\
6. Primär Power-Layer\\
\textbf{Layer 1 (Top-Layer – Hochstrom und Leistungsführung):} Layer 1\&6 tragen die Hauptlast der Leistungsversorgung. Da diese Layer die dickste Kupferschicht aufweist (1 oz Kupfer pro Layer), werden sie für die Führung der 48V Versorgung und der Motorphasenströme genutzt. Leiterbahnen, die große Ströme führen, wie z. B. die H-Brücken für den BLDC-Motor, werden auf diesem Layer platziert. Breite Leiterbahnen und großzügige Kupferflächen gewährleisten einen niedrigen Widerstand und vermeiden unerwünschte Erwärmung. Der Platzbedarf für Hochstromverbindungen wird optimiert, um Spannungsabfälle und Leistungsverluste zu minimieren.\\
\textbf{Layer 2 (Signal Ground Layer):} Layer 2 dient als dedizierte Massefläche für die gesamte Leiterplatte. Diese Fläche erfüllt zwei Hauptfunktionen:
\textbf{Potentialreferenz:} Komponenten, die auf Massepotential arbeiten, können über Vias direkten Zugang zu diesem Layer erhalten, wodurch Massewege verkürzt werden und störungsfreier Betrieb gewährleistet ist.
\textbf{Schirmung:} Die großflächige Massefläche direkt unter den aktiven Komponenten dient als elektromagnetischer Schutzschild. Sie verhindert, dass hochfrequente Signale oder Störfelder von den oberflächennahen Komponenten in tiefere Layer eindringen und dort empfindliche Signale beeinträchtigen.\\
\textbf{Layer 3\&4 (Signal-Layer – Analog- und Digitalsignale):} Layer 3 und 4 sind für die Führung von Steuersignalen und Kommunikationsleitungen vorgesehen. Diese Layer wurden aufgrund ihrer Position in der Mitte des PCB-Stacks gewählt, da sie dort vor externen Störquellen am besten geschützt sind. \textbf{Layer 3 (Digital-Signale):} Hier werden digitale Steuersignale wie Kommunikationsleitungen (UART, I²C) geführt. Durch die Trennung von analogen und digitalen Signalen wird sichergestellt, dass hochfrequente Schaltimpulse die Integrität der analogen Signale nicht beeinträchtigen.
\textbf{Layer 4 (Analog-Signale):} Dieser Layer führt empfindliche analoge Signale, z. B. Spannungs- und Strommessleitungen, um sicherzustellen, dass diese möglichst störungsfrei und fern von digitalen Schaltfrequenzen verlaufen.\\
\textbf{Layer 5 (Kleinspannungs-Versorgungsebene):} Layer 5 führt großflächige Versorgungsnetze für 12V, 5V und 3.3V. Diese Spannungen versorgen Mikrocontroller, Sensoren und andere Niederspannungskomponenten. Die großzügigen Kupferflächen minimieren Spannungsabfälle und ermöglichen eine gleichmäßige Spannungsverteilung über die gesamte Platine. Vias ermöglichen es, die Spannungen direkt an die benötigten Stellen zu führen, wodurch die Anzahl langer Leiterbahnen reduziert wird.\\
\textbf{Layer 6 (Bottom-Layer – Hochstrom und Leistungsführung):} Layer 6 fungiert als ergänzende Leistungsebene zu Layer 1 und trägt ebenfalls Hochstrompfade, jedoch auf der Unterseite der Platine. Er wird für die Rückführung von Leistungsströmen und zur Anbindung an Motorphasen verwendet. Durch die symmetrische Anordnung von Layer 1 und Layer 6 wird die Strombelastung der Platine gleichmäßig verteilt und die thermische Belastung reduziert.\\
\\
Diese strukturierte Aufteilung gewährleistet eine klare Trennung von Leistungs- und Signalpfaden, reduziert EMV-Probleme und verbessert die allgemeine Zuverlässigkeit der Schaltung. Besondere Aufmerksamkeit wurde darauf gelegt, kritische Signale nicht unter Leistungsinduktivitäten oder großen Leistungstransistoren zu führen, um unerwünschte Koppelungen und Störungen zu vermeiden.\\
Die Leiterbahnbreite der Hochstromleitungen beträgt mindestens 700 mil, um Spannungsabfälle und eine übermäßige Erwärmung zu minimieren.
Der MOSFET-Heatsink ist zusätzlich mit der Power-Ground-Fläche verbunden, um die Wärmeableitung zu verbessern.
Thermisch kritische Bauteile, wie beispielsweise Schaltregler, sind mit speziellen Kupferflächen versehen.
Für eine optimale Wärmeabfuhr wurden In-Pad-Vias integriert, um die Wärme effizient von den Bauteilen zur Massefläche abzuleiten.

\chapter{Software}
Dieses Kapitel bietet eine detaillierte Beschreibung der Softwarearchitektur und geht auf die wichtigsten Module ein, die die Funktionalität des Systems gewährleisten. Von der Initialisierung der Hardware über die Motorsteuerung bis hin zur Benutzerinteraktion deckt die Software eine Vielzahl von Aufgaben ab, die in den folgenden Unterkapiteln erläutert werden.\\
Den vollständigen Quellcode zu diesem Projekt finden Sie auf GitHub unter github.com
/leonreeh/E-Bike-ECU $\Rightarrow$ BLDC-ESC-Firmware.\\
\\
\textbf{main.c/h }Board Initialisierung, Mainloop und state machine\\
\textbf{BLDC.c/h}  Interpretation des Hall Sensoren und setzen der Mosfet-Brücke\\
\textbf{liquidcrystal\_i2c.c/h} Kommunikation mit dem LCD display\\
\textbf{Mymath.c/h} mathematische Hilfsfunktionen und Berechnungen\\
\textbf{stm32f4xx\_it.c/h} Timer Interrupt-Routine, für zeitabhängige Funktionen (zb Geschwindigkeitsberechnung\\
\begin{figure}[ht]
\begin{center}
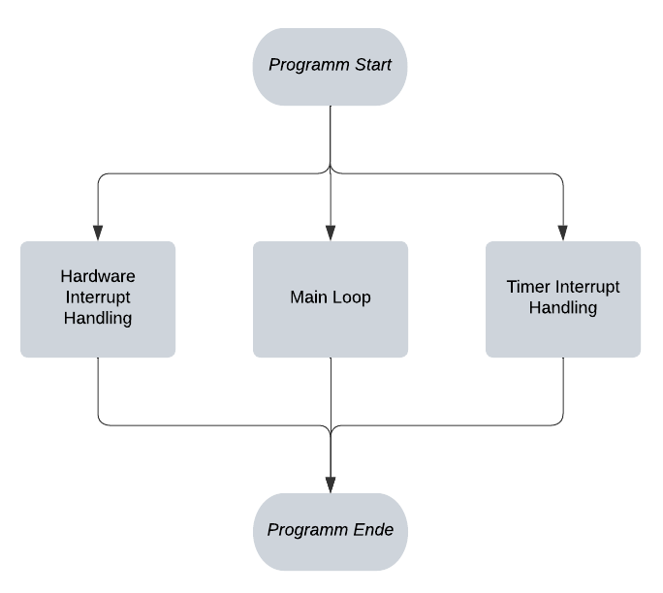
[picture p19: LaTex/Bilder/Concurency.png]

\caption{Prozess-Parallelität}
\label{concur}
\end{center}
\end{figure}
\newpage
\section{Prozesse \& Softwarearchitektur}
Das gesamte Programm wird in vereinfachter Form durch drei parallel arbeitende Prozesse gesteuert: der \textbf{Main Loop}, den \textbf{Timer Interrupt} und den \textbf{Hardware Interrupt}. Diese Prozesse übernehmen unterschiedliche Aufgaben, um eine effiziente und stabile Steuerung sicherzustellen.\\

\paragraph{\textbf{1. Der Hardware Interrupt}} wird für zeitkritische Ereignisse verwendet und reagiert unmittelbar auf bestimmte Signale. Diese Funktionen beinhalten:
Interpretation der Motor-Hall-Sensoren (Ermittlung der Motorposition)
Erkennung des Hinterrad-Bremshebels (Einleitung des Bremsvorgangs)
Verarbeitung des Hardware Fault Signals (Kritische Fehlererkennung).\\
\paragraph{\textbf{2. Der Timer Interrupt}} arbeitet mit festen Zeitintervallen und dient der periodischen Ausführung zeitgesteuerter Aufgaben. Wie der Berechnung der Drehzahl (alle 100 ms), Übertragung von Daten an das Display (alle 500 ms), Software Fault Timeout (30s).
\begin{figure}[ht]
\begin{center}
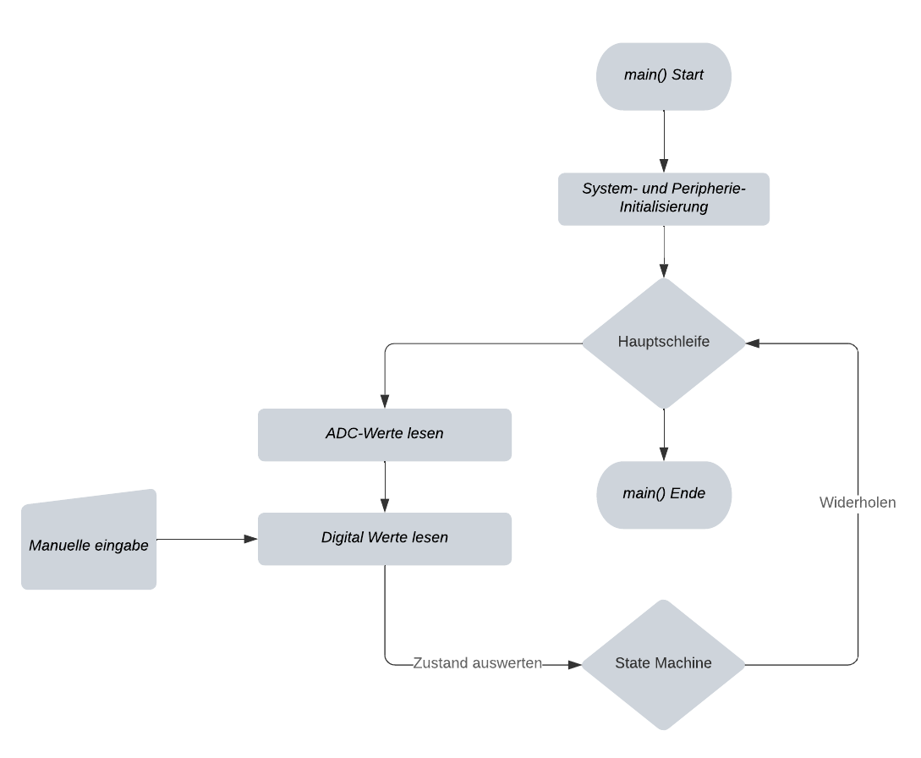
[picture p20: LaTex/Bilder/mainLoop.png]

\caption{Ablauf-Diagramm Main Loop}
\label{mainl}
\end{center}
\end{figure}
\paragraph{\textbf{3. Die Main Loop}} bearbeitet zyklisch alle nicht zeitkritischen Aufgaben.
Dies beinhaltet: Einlesen\&Konvertieren der ADC-Messwerte, Abfrage der Bedientaster, Verarbeitung der Zustandsmaschine (State Machine), Setzen der digitalen Ausgänge (z. B. Beleuchtung, Lüftersteuerung).

\subsection{Zustandsautomat/State Machine}
Um die Vielzahl der Funktionen des Mikrocontrollers effizient und sicher zu verwalten, wurde in der Main Loop ein Zustandsautomat (State Machine) implementiert. Dieses Prinzip basiert auf der Definition von klaren Zuständen und Übergängen zwischen diesen, abhängig von bestimmten Bedingungen oder Ereignissen. Ein Zustandsautomat ist ein Kontrollflussmodell, das aus folgenden Elementen besteht:\\
\textbf{Zustände:} Definieren die aktuellen Betriebsmodi oder Aufgaben des Systems (z. B. Initialisierung, Normalbetrieb, Fehlerzustand).\\
\textbf{Übergänge:} Beschreiben die Bedingungen, unter denen das System von einem Zustand in einen anderen wechseln kann.\\
\textbf{Ereignisse oder Bedingungen:} Lösen die Übergänge zwischen Zuständen aus (z. B. Sensorwerte, Timer, Benutzereingaben).\\

\begin{figure}[ht]
\begin{center}
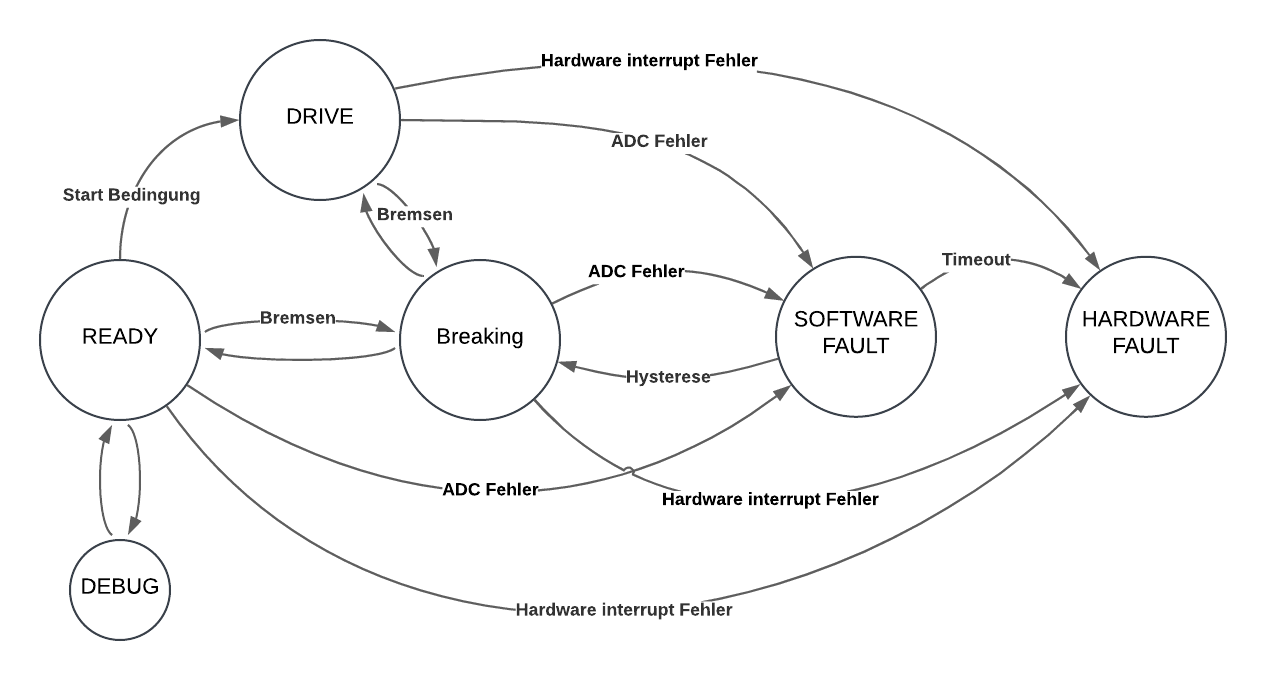
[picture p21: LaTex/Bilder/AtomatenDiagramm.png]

\caption{Zustandsautomaten Diagramm}
\label{StateM}
\end{center}
\end{figure}
\newpage

Die in Abbildung \ref{StateM} dargestellten Zustände:\\
\textbf{READY:}\\
Nach Abschluss der Systeminitialisierung wechselt der Controller in den „Standby“-Zustand.
In diesem Zustand bietet das Geräte folgende Funktionen:
Steuerung der Beleuchtung,
Initialisierung des Motors,
Aktivierung der Lüfter bei Temperaturen (T) $\geq$ 60°C.\\
\textbf{DRIVE:}\\
Dieser Zustand repräsentiert den Fahrbetrieb. Mit den Funktionen:
Steuerung der Beleuchtung,
Volle Motorleistung,
Aktivierung der Lüfter bei T $\geq$ 60°C.\\
\textbf{BRAKING:}\\
Dieser Zustand repräsentiert das aktive Motorbremsen.
Zustandsfunktionen:
Steuerung der Beleuchtung,
Motor im Bremsbetrieb,
Aktivierung der Lüfter bei T $\geq$ 60°C.\\
\textbf{SOFTWARE FAULT:}\\
In diesem Zustand wird der Motor gestoppt, Beleuchtungselemente werden deaktiviert, um Last zu reduzieren.\\
\textbf{HARDWARE FAULT:}\\
Dieser Zustand gilt als kritisch, er kann nur durch Aus- und erneutes Einschalten des Geräts verlassen werden und Blockiert alle Funktionen wie Motor und Beleuchtung-Steuerung.
Optional kann das gerät sich selbstständig abschalten durch öffnen des Selbsthalterelais.\\
\\
Übergänge wie in Abbildung \ref{StateM} dargestellte:\\
\textbf{Start:}\\
Bedingung: Das Gerät befindet sich im READY-Zustand, Drehzahl = 0,
Der Nutzer drückt den Start-Taster oder bewegt den Gas-Griff, woraufhin das Gerät in den DRIVE-Zustand wechselt und die Fahrt beginnt.\\
\textbf{Bremsen:}\\
Der Nutzer betätigt während der Fahrt den Bremshebel, wodurch ein Hardware-Interrupt ausgelöst wird.
Der Motor wechselt vom Antriebsmodus in den Bremsmodus.
Sobald der Motor bis zum Stillstand abgebremst ist, wechselt das Gerät zurück in den READY-Zustand. Wird der Bremshebel losgelassen, bevor die Drehzahl 0 erreicht, kehrt das Gerät in den DRIVE Zustand zurück.\\
\textbf{ADC-Fehler:}\\
Tritt ein ADC-Messwert über einen definierten Grenzwert (z. B. Kühlkörpertemperatur > 100°C), betritt das System den SOFTWARE FAULT-Zustand. Dieser Zustand kann nur verlassen werden in dem die Temperatur wieder unter 80°C fällt. Dies passiert über den BRAKE Zustand, um versehentliches Start des Motors zu vermeiden.\\
\textbf{Timeout:}\\
Mit dem betreten des SOFTWARE FAULT Zustands wird ein 30s Timer gestartet, wenn dieser Zustand nicht vor ablaufen dieses Timers verlässt. Wechselt es den HARDWARE FAULT-Zustand.\\
\textbf{Hardware-Interrupt-Fehler:}
Beispiel Die Spannung Des Akkus fällt unter 42.9V löst die Hardware Messschaltung (siehe Schaltplan Abbildung \ref{UV}) aus und betätigt damit den Fault Interrupt-Pin (siehe Schaltplan Abbildung \ref{orGate}). 

\section{Source Code}
Um die Dokumentation kompakt und übersichtlich zu gestalten, konzentriert sich dieser Abschnitt ausschließlich auf die Funktionen des Mikrocontrollers, die für die Hauptlogik und Steuerung des Systems entscheidend sind. Allgemeine Quellcode-Elemente wie die Konfiguration von GPIOs, Timern oder Middleware werden bewusst vernachlässigt. Die hier erklärten Source Code ausschnitte finden sie im Anhang unter Source Code
\subsection{Main.c/h}
\paragraph{\textbf{Main Loop}} siehe Anhang Source Code~\ref{main}\\
implementiert eine Endlosschleife (while(1)), die eine Zustandsmaschine zur Steuerung verschiedener Betriebszustände verwendet. In jedem Schleifendurchlauf werden zunächst Eingaben durch readADCs(), readDI() erfasst und mit doADCs() setDO() verarbeitet. Anschließend wird ein switch-Statement basierend auf der aktuellen Systemzustandsvariable (STATE) ausgeführt. Je nach Zustand (READY, DRIVE, BREAK, etc) werden entsprechende Funktionen aufgerufen, um den Systemstatus zu verwalten, beispielsweise ready(). In fehlerhaften Zuständen (SWFAULT und HWFAULT) werden die digitalen Ausgänge (DO) mit resetDO() zurückgesetzt, während in regulären Betriebszuständen setDO() aktiviert wird. Zusätzlich wird ein LCD-Display alle 500 ms aktualisiert, wenn der Zähler timcc den Wert 5 erreicht. Am Ende jedes Schleifendurchlaufs wird eine Verzögerung von 25 ms mit HAL\_Delay(25); eingefügt, um den Prozessor zu entlasten.
\paragraph{\textbf{readADCs()}} siehe Anhang Source Code~\ref{readADC}\\
Die Funktion readADCs liest analoge Werte von drei unterschiedlichen Quellen (Spannung, Strom und Temperatur) ein und speichert die Ergebnisse in einem globalen Array ADC\_VAL.
\paragraph{\textbf{doADCs()}} siehe Anhang Source Code~\ref{doADC}\\
Die Funktion doADCs analysiert die erfassten ADC-Werte, überprüft Grenzwerte und steuert Systemkomponenten wie den Lüfter basierend auf den Messwerten. Sie verwaltet zudem Zustandsübergänge und erkennt Fehlerzustände.
\paragraph{\textbf{readDI()}} siehe Anhang Source Code~\ref{readDI}\\
Die Funktion readDI liest den Zustand von vier digitalen Eingängen (Tastern) ein und aktualisiert ein globales Array but, das diese Zustände speichert.
\paragraph{\textbf{setDO()}} siehe Anhang Source Code~\ref{setDO}\\
Die Funktion setDO setzt digitale Ausgänge basierend auf dem aktuellen Zustand der Taster (gespeichert im globalen Array but) und steuert damit Systemkomponenten wie Licht, Blinker und einen Debug-Modus.
\paragraph{\textbf{ready()}} siehe Anhang Source Code~\ref{ready}\\
Die Funktion ready prüft den Gasgriff und initialisiert den Motor, falls die Startbedingungen erfüllt sind. Wenn der Gasgriff eine bestimmte Schwelle überschreitet, wird das System in den Zustand DRIVE versetzt und der BLDC-Motor gestartet.
\paragraph{\textbf{drive()}} siehe Anhang Source Code~\ref{drive}\\
Die Funktion drive liest den Gasgriffwert ein, berechnet den entsprechenden Duty-Cycle und aktualisiert diesen, um die Motorgeschwindigkeit während des Fahrmodus zu steuern. Bei einem Fehler in der ADC-Konvertierung wird der Duty-Cycle auf einen sicheren Wert gesetzt, und ein Fehlerzustand ausgelöst.
\paragraph{\textbf{breaking()}} siehe Anhang Source Code~\ref{break}\\
Die Funktion breaking setzt den Motor in den Bremsmodus, indem sie die PWM-Signale stoppt und die Motorphasen kurzschließt, um die Bewegung zu verlangsamen oder zu stoppen
\paragraph{\textbf{swfault()}} siehe Anhang Source Code~\ref{swfault}\\
Die Funktion swfault wird aufgerufen, wenn ein Softwarefehler erkannt wird. Sie setzt das System in einen sicheren Zustand durch Aktivierung des Bremsmodus und überwacht, ob der Fehlerzustand über einen definierten Timeout hinaus anhält.
\paragraph{\textbf{hwfault()}} siehe Anhang Source Code~\ref{hwfault}\\
Die Funktion hwfault behandelt einen dauerhaften Hardwarefehlerzustand. Sie stoppt das System vollständig und zeigt eine Fehlermeldung an, während sie auf einen Neustart (Power-On-Reset) wartet.\\
\paragraph{\textbf{HAL\_GPIO\_EXTI\_Callback()}} siehe Anhang Source Code~\ref{interrupt}\\
Die Funktion HAL\_GPIO\_EXTI\_Callback wird aufgerufen, wenn ein externer GPIO-Interrupt ausgelöst wird. Sie verarbeitet verschiedene Arten von Interrupts, darunter Brems-, Hardwarefehler- und Hall-Sensor-Interrupts, abhängig vom Zustand des Systems und dem auslösenden Pin.\\
\paragraph{\textbf{handleHardwareFaultInterrupt()}} siehe Anhang Source Code~\ref{hwint}\\
Wechselt bei Hardwarefehlern in den entsprechenden Fehlerzustand. Optional: Fehlerdiagnose kann implementiert werden.
\paragraph{\textbf{handleBreakInterrupt()}} siehe Anhang Source Code~\ref{brint}\\
Die Funktion handleBreakInterrupt verarbeitet den Interrupt, der durch das Betätigen oder Loslassen des Bremshebels ausgelöst wird. Sie wechselt den Systemzustand zwischen BREAK und READY.
\paragraph{\textbf{handleHallSensorInterrupt()}} siehe Anhang Source Code~\ref{senint}\\
Die Funktion handleHallSensorInterrupt verarbeitet Interrupts, die durch Änderungen an den Hall-Sensoren ausgelöst werden. Sie zählt die Rotationsschritte des Motors, ermittelt die aktuelle Rotorposition und steuert die Motorphasen basierend auf trapezförmiger Kommutierung.

\subsection{BLDC.c/h}
\paragraph{\textbf{hallState()}} siehe Anhang Source Code~\ref{hallS}\\
Die Funktion hallState interpretiert die Zustände der Hall-Sensoren (ein Array mit drei Werten) und ermittelt die aktuelle Position des Rotors in Bezug auf die elektrische Kommutationsstufe (zwischen 0 und 5).
\paragraph{\textbf{commutator()}} siehe Anhang Source Code~\ref{commuta}\\
Die Funktion commutator steuert die drei Phasen eines BLDC-Motors basierend auf der Kommutatorposition, dem gewünschten Duty-Cycle (PWM-Signal) und der Drehrichtung des Motors.
\paragraph{\textbf{initBLDC()}} siehe Anhang Source Code~\ref{initBL}\\
Die Funktion initBLDC initialisiert den BLDC-Motor basierend auf den aktuellen Hall-Sensor-Zuständen.
\paragraph{\textbf{BLDCbreak()}} siehe Anhang Source Code~\ref{BLbreak}\\
Die Funktion BLDCbreak versetzt den BLDC-Motor in den Bremsmodus, indem sie alle Phasen des Motors kurzschließt und die PWM-Ausgabe deaktiviert.
\subsection{liquidcrystal\_i2c.c/h}
\paragraph{\textbf{lcd struct}} siehe Anhang Source Code~\ref{struct}\\
Die Struktur lcd\_ar wird verwendet, um Daten und Cursorpositionen für die Aktualisierung eines LCD-Displays zu speichern. Sie enthält die wichtigsten Systemparameter sowie deren Positionen auf dem Display.
\paragraph{\textbf{HD44780\_SetCursor()}} siehe Anhang Source Code~\ref{setC}\\
Die Funktion HD44780\_SetCursor setzt die Position des Cursors auf einem HD44780-kompatiblen LCD-Display. Die Position wird durch die Spalte (col) und die Zeile (row) angegeben.
\paragraph{\textbf{HD44780\_PrintStr()}} siehe Anhang Source Code~\ref{print}\\
Die Funktion HD44780\_PrintStr schreibt eine Zeichenkette (String) auf ein HD44780-kompatibles LCD-Display.
\paragraph{\textbf{Init\_lcd\_ar()}} siehe Anhang Source Code~\ref{initLCD}\\
Die Funktion Init\_lcd\_ar initialisiert eine Instanz der Struktur lcd\_ar mit Standard-Cursor-Positionen und voreingestellten Anzeigewerten auf einem HD44780-kompatiblen LCD-Display.
\paragraph{\textbf{update\_lcd\_val()}} siehe Anhang Source Code~\ref{upLCD}\\
Die Funktion update\_lcd\_val aktualisiert sowohl die Daten in einer lcd\_ar-Struktur als auch die Anzeige auf einem HD44780-kompatiblen LCD-Display mit neuen Sensorwerten.
\subsection{Mymath.c/h}
\paragraph{\textbf{pid struct}} siehe Anhang Source Code~\ref{pid}\\
Die Struktur pid\_f\_t wird verwendet, um die Parameter und Zustandsvariablen eines PID-Reglers (Proportional-Integral-Differential-Regler) zu speichern.\\
\paragraph{\textbf{map()}} siehe Anhang Source Code~\ref{map}\\
Die Funktion map skaliert einen Wert aus einem Bereich (Eingabebereich) in einen anderen Bereich (Zielbereich). Dies wird häufig verwendet, um Werte zwischen unterschiedlichen Skalen umzuwandeln, z. B. ADC-Werte in eine PWM-Skala.\\
\textbf{Formel:}\\ $mapped value = (\frac{x-in_{ min }}{in_{ max }-in_{ min }  })\times (out_{ max }-out_{ min })+out_{ min }$
\paragraph{\textbf{adc\_volt()}} siehe Anhang Source Code~\ref{adcV}\\
Die Funktion adc\_volt berechnet die Eingangsspannung (Vin) basierend auf einem Rohwert des ADC (val). Sie verwendet ein Spannungsteiler-Netzwerk, um die tatsächliche Spannung am Eingang zu bestimmen.\\
\textbf{Formel:}\\ $V_{ adc } = \frac{ val }{ 4095 } \times V_{ cc }$ ; $V_{in} = V_{adc} \times \left( \frac{R_1 + R_2}{R_2} \right)$
\paragraph{\textbf{adc\_cur()}} siehe Anhang Source Code~\ref{adcC}\\
Die Funktion adc\_cur berechnet den Strom in Ampere basierend auf einem Rohwert des ADC (val), einem Shunt-Widerstand und einem Verstärkungsfaktor.\\
\textbf{Formel:}\\ $V_{ adc } = \frac{ val }{ 4095 } \times V_{ cc }$ ; $V_{\text{adc\_adjusted}} = V_{\text{adc}} - 1,65V$ ; $V_{\text{shunt}} = \frac{V_{\text{adc\_adjusted}}}{\text{amplification\_factor}}$ ; $\text{current} = \frac{V_{\text{shunt}}}{R_{\text{shunt}}}$
\paragraph{\textbf{adc\_temp()}} siehe Anhang Source Code~\ref{adcT}\\
Die Funktion adc\_temp berechnet die Temperatur in Grad Celsius basierend auf einem Rohwert des ADC (val), der Spannungsteilerkonfiguration eines NTC-Thermistors (R1) und der Steinhart-Hart-Gleichung (vereinfachte Form mit Beta-Parameter).\\
\textbf{Formel:}\\ $V_{ adc } = \frac{ val }{ 4095 } \times V_{ cc }$ ; $R_1 = R_2 \times \left( \frac{V_{cc}}{V_{\text{adc}}} - 1.0 \right)$ ; $T = \frac{ 1.0 }{\frac{ 1 }{ T_{ 0 } } + \frac{ 1 }{ B } \times 1og(\frac{ R1 }{ R0 }) }$
\paragraph{\textbf{rpm\_tokmh()}} siehe Anhang Source Code~\ref{kmh}\\
Die Funktion rpm\_tokmh berechnet die Geschwindigkeit in Kilometern pro Stunde (km/h) basierend auf der Motordrehzahl (RPM) und dem Radumfang(U).\\
\textbf{Formel:}\\ $m/min = RPM \times U$; $kmh = \frac{ m/min \times 60min }{ 1000m }$
\subsection{stm32f4xx\_it.c/h}
\paragraph{\textbf{TIM2\_IRQHandler()}} siehe Anhang Source Code~\ref{tim2}\\
Die Funktion TIM2\_IRQHandler ist der Interrupt-Handler für den Timer TIM2, der mit einer Frequenz von 100 ms ausgelöst wird. Sie führt mehrere systemkritische Aufgaben aus, einschließlich der Berechnung der Drehzahl (RPM) und Geschwindigkeit sowie der Verwaltung von Zeitmessungen und Zuständen. Motor Sensor interrupt zähler (hallCC), Motor Polpaare (24).\\
\textbf{Formel:}\\
$x = hallCC \times 10 $ ; $rev = \frac{x}{24}$ ; $RPM = rev \times 60$
\newpage
\section{Controller Konfiguration}
Controller Pinning und Konfiguration basiert auf dem opensource VESC 6.4 Schaltplan und wurden mit Hilfe des STM32CubeIDE Configuratos erweitert.
\begin{figure}[ht]
\begin{center}
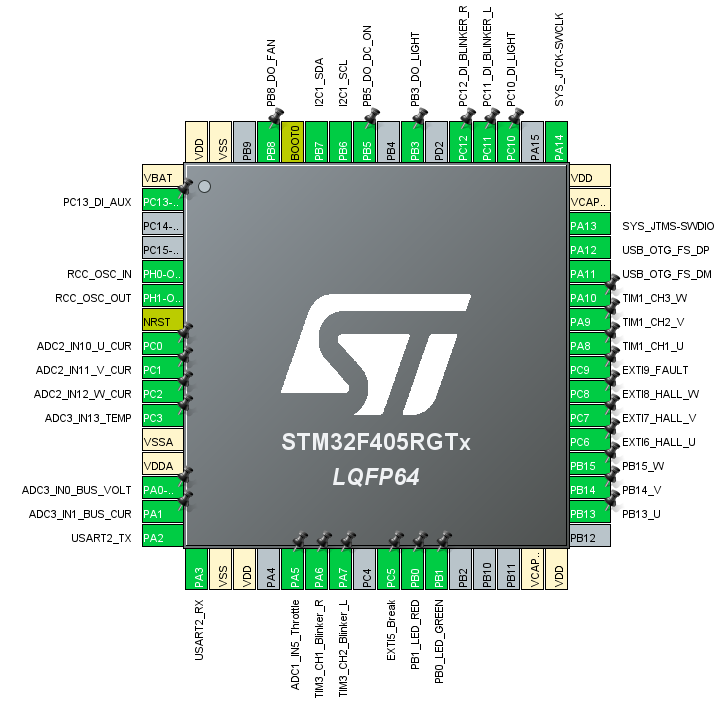
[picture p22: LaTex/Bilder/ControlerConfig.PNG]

\caption{Pin Konfiguration}
\label{pinning}
\end{center}
\end{figure}

\begin{figure}[ht]
\begin{center}
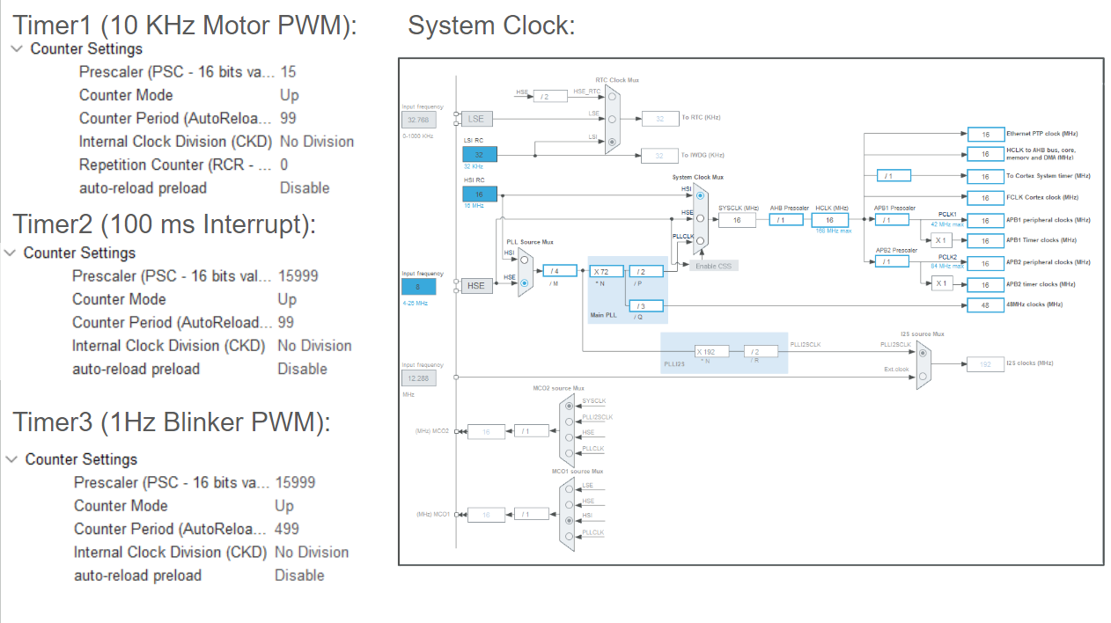
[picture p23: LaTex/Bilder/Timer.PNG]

\caption{System Clock Konfiguration}
\label{clock}
\end{center}
\end{figure}

\chapter{Gehäuse}
Die STL-Dateien der Gehäuse sind auf der Projekt-GitHub-Repository
github.com/leonreeh/E-Bike-ECU $\Rightarrow$ Gehäuse STL verfügbar. 
\begin{figure}[ht]
\begin{center}
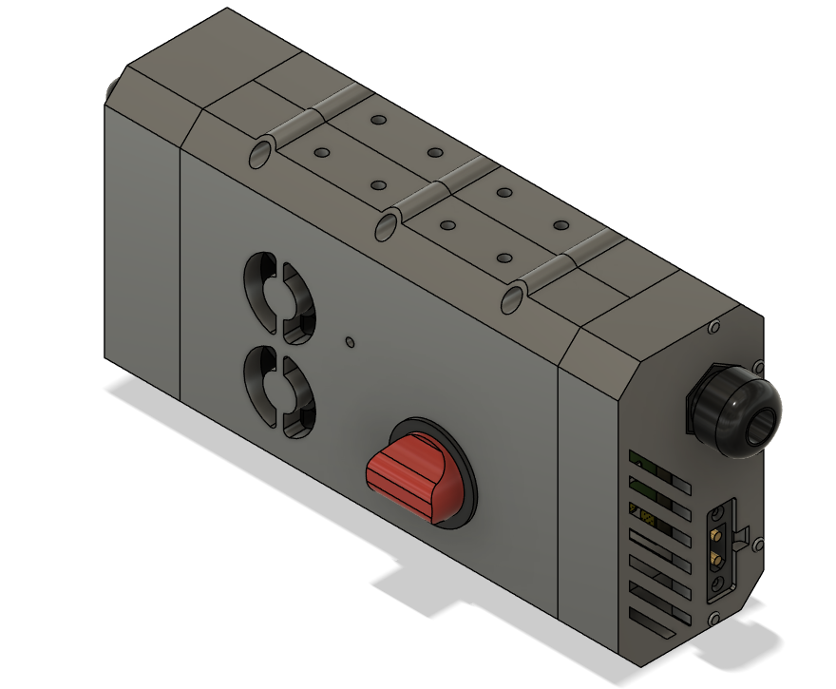
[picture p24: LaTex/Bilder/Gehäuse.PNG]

\caption{Gehäuse}
\label{Gehäuse}
\end{center}
\end{figure}
\section{Mechanische Eigenschaften}
\textbf{Material:} ASA (Acrylnitril-Styrol-Acrylat) wurde aufgrund seiner robusten mechanischen Eigenschaften gewählt. Es bietet hohe Temperatur- und UV-Beständigkeit und lässt sich einfach weiterverarbeiten. Das Material ist besonders geeignet für Anwendungen, die ständiger Witterung oder mechanischer Belastung ausgesetzt sind.\\
\textbf{Dimensionen:} Die Außenmaße betragen 272 × 140 × 77 mm, was ausreichend Platz für die notwendigen Elektronikkomponenten bietet und eine kompakte Integration ermöglicht.
\newpage
\section{Konstruktion}
Das Gehäuse besteht aus vier modularen Einzelteilen:
\textbf{Platinenträger:} Hier wird die elktronik mit hilfe von M3 schrauben befestigt
\textbf{Vorder- und Rückseite:} Diese Teile werden mithilfe von 3 × 60 mm Nägeln und einem speziellen ASA-Kleber dauerhaft mit dem Platinenträger verbunden. Dies sorgt für eine robuste und langanhaltende Fixierung.
\textbf{Deckel:} Der Deckel wird mit M4-Schrauben befestigt, was einen einfachen Zugriff auf die Elektronik bei Wartungsarbeiten ermöglicht.\\
Zur Anbindung von verschraubbaren Teilen werden sogenannte \textbf{Heatset-Inserts} verwendet. Diese bestehen aus Messing und können mithilfe eines Lötkolbens in das Kunststoffmaterial eingebracht werden. Dadurch entsteht ein langlebiges und stabiles Metallgewinde, das sich ideal für wiederholtes Verschrauben eignet.
M4 Inserts: Zum sicheren Verschrauben des Deckels.
M3 Inserts: Für die Montage der Platine und Lüfter.
\section{Gehäuse Komponenten}
\begin{figure}[ht]
\begin{center}

\caption{Front}
\label{Front}
\end{center}
\end{figure}
Lufteinlässe: Passive Kühlung durch strategisch platzierte Lufteinlässe für optimale Wärmeableitung.
Anschlussbuchse: Eine XT90-Buchse dient zur Verbindung mit dem Akku. Diese ist für hohe Ströme ausgelegt und sorgt für sichere Energieübertragung.
Kabelzugentlastung: Eine PG17-Zugentlastung stellt sicher, dass die Leitungen für Bedienelemente und das Display sicher fixiert sind und keine mechanischen Belastungen auf die internen Verbindungen wirken.
Befestigung: Die Frontseite wird mit 5 Nägeln am Platinenträger montiert.
\newpage
\begin{figure}[ht]
\begin{center}

\caption{Rückseite}
\label{back}
\end{center}
\end{figure}
Kabelzugentlastungen:
PG11 für die Motorleitungen,
PG7 für die Heckbeleuchtung,
PG7 für die Heckblinker,
Befestigung: Auch die Rückseite wird mit 5 Nägeln sicher am Platinenträger fixiert.
\begin{figure}[ht]
\begin{center}

\caption{Platinenträger}
\label{pholder}
\end{center}
\end{figure}
Heatset Inserts: M4 Inserts für die Montage des Deckels, M3 Inserts für die sichere Befestigung der Platine.
PCB-Standoffs: Integrierte PCB-Standoffs sorgen für zusätzliche Stabilität und unterstützen die Elektronik gegen Verbiegen. Diese Konstruktion minimiert mechanische Belastungen auf die Platine.
\newpage
\begin{figure}[ht]
\begin{center}

\caption{Deckel}
\label{Deckel}
\end{center}
\end{figure}
Lüfter-Standoff: Ein erhöhter Bereich zur direkten Positionierung eines Lüfters über dem Kühlkörper, um die Wärmeableitung zu verbessern.
Relaishalter: Speziell designet Aussparungen sorgen für die sichere Positionierung und Fixierung des Relais.
Befestigungsbohrung: Eine Bohrung mit Registrierung ermöglicht die Montage eines Not-Aus-Schalters an einer zugänglichen Stelle.\\
\\
\textbf{Gehäuse Stückliste:}\\
\\
\begin{tabular}[h]{l|c|r}
\label{GeStk}
\textbf{Name} & \textbf{Stückzahl} & \textbf{Beschreibung} \\
\hline
Platinenträger & 1 & STL file für 3D druck \\
\hline
Deckel & 1 & STL file für 3D druck \\
\hline
Front & 1 & STL file für 3D druck \\
\hline
Rückseite & 1 & STL file für 3D druck \\
\hline
M3S Gewindeeinsatz & 20 & M3 gewinde insert \\
\hline
M4 Gewindeeinsatz & 6 & M4 gewinde insert \\
\hline
XT90E-M & 1 & Hochstrom Einbaustecker \\
\hline
PG17 & 1 & Zugentlastung \\
\hline
PG11 & 1 & Zugentlastung \\
\hline
PG7 & 2 & Zugentlastung \\
\end{tabular}

\part{Entwicklungsprozess und Relevante Konzepte}
In diesem Kapitel widme ich mich dem \textbf{Entwicklungsprozess} und den \textbf{relevanten Konzepten}, die für die Realisierung des Projekts von zentraler Bedeutung sind. Ziel ist es, einen Einblick in die methodische Herangehensweise und die zugrunde liegenden Entscheidungen zu geben, die den Weg von der ersten Idee bis hin zu einem funktionalen Prototypen geebnet haben.\\
Der Entwicklungsprozess folgt einer klar strukturierten Methodik – von der Planung über die Designphase bis hin zur Umsetzung. Zentrale Herausforderungen, wie die Auswahl geeigneter Hardware-Komponenten und die Entwicklung eines zuverlässigen Steuerungssystems, wurden durch einen systematischen Ansatz und eine speziell auf das Projekt zugeschnittene Strategie bewältigt. Dabei wurde das komplexe Gesamtsystem in kleinste funktionale Einheiten unterteilt, die in einzelnen Entwicklungsphasen überprüft wurden. Ziel war es, Designfehler frühzeitig zu erkennen und die Integration in das Gesamtsystem zu erleichtern.
\chapter{Entwicklungsprozess}
\paragraph{Planung}
Nach der Auswahl des Projektthemas begann die Recherche zu den grundlegenden Aspekten des E-Bikes. Wesentliche Fragestellungen, die beantwortet werden mussten, waren:\\
\textbf{Welcher Motor und wie wird er angesteuert?\\}
Im Bereich der E-Mobilität ist die Wahl der Motorart eindeutig: Der B\textbf{rushless DC Motor (BLDC)}. Aufgrund seines wartungsfreien Designs und seiner hohen Leistungsdichte eignet er sich ideal für Antriebssysteme und wird in verschiedensten Anwendungen von E-Bikes bis hin zu Elektroautos eingesetzt.\\
Für dieses Projekt fiel die Entscheidung auf einen diskreten BLDC-Hub-Motor. Ein Hub-Motor ist direkt in der Radnabe integriert, wodurch keine Änderungen am Fahrradrahmen erforderlich sind. Diese Bauweise erleichtert die Integration in bestehende Fahrräder erheblich. Zudem wird der Kettenantrieb des Fahrrads nicht belastet, da die Kraftübertragung direkt über das Rad erfolgt.\\
\textbf{Welcher Akku wird verwendet?\\}
Die am häufigsten in E-Bikes vertretenen Akkusysteme sind 7S (24V), 9S (32V) und 13S (48V). Mit einer Zielsetzung von 1 kW Leistung fiel die Wahl auf ein 48V-System. Diese Entscheidung ermöglicht es, den Stromfluss gering zu halten und dadurch die ohmschen Verluste in Leitungen und Steckverbindungen zu minimieren.\\
Basierend auf dieser Spannung konnten erste Hardware-Anforderungen dimensioniert werden, beispielsweise der Eingangsspannungsbereich des Netzteils, um eine stabile und effiziente Energieversorgung sicherzustellen. Siehe Anhang Entwicklung \ref{stateofC}\\
\textbf{Welche Zusatzfunktionen?}\\
Zusätzliche Features wie Beleuchtung und ein Display sollten integriert werden, um den Funktionsumfang zu erweitern und die Benutzererfahrung zu verbessern.

\paragraph{Designphase}
Für die Motorsteuerung wurde das Open-Source-„VESC-Projekt“ als Basis gewählt. Dieses ist bekannt für seine robuste Hardware für Akku betriebene Antriebssysteme im Kilowatt Bereich, sowie eine breite und modulare Softwarearchitektur. Durch diese Entscheidung wurde eine der komplexesten Herausforderungen des Projekts – die Auswahl eines geeigneten Mikrocontrollers – erheblich erleichtert. Die Vielfalt an verfügbaren Mikrocontrollern, z. B. von Herstellern wie Renesas, STMicro und NXP, und die unterschiedlichen Spezifikationen wie Speichergröße, 16/32-Bit-Systeme, Anzahl von Interrupts und ADC-Pins, machten diese Entscheidung besonders anspruchsvoll.\\
Aus dem VESC 6.4-Referenzdesign wurde die Mikrocontroller-Auswahl sowie dessen Pinbelegung übernommen, während der restliche Schaltplan und die gesamte Software vollständig eigenständig entwickelt wurden.
\newpage
\begin{figure}[ht]
\begin{center}

\caption{Designphasen}
\label{designp}
\end{center}
\end{figure}
\newpage
\chapter{Designphasen}
\section{Designphase 1}
\paragraph{Mikrocontroller}
Für die Inbetriebnahme des Mikrocontrollers wurde eine kompakte 2-Layer-Leiterplatte entworfen, die alle notwendigen Komponenten enthält, um eine funktionale und stabile Umgebung für die Softwareentwicklung zu gewährleisten. Die Leiterplatte umfasst:
\textbf{3.3V-Versorgung} zur Stromversorgung des Mikrocontrollers.
\textbf{Clock-Oszillator} für die Systemtaktung.
\textbf{Debug-LEDs}, die den Status oder Fehlerzustände anzeigen.
\textbf{Programmierschnittstelle}, um den Mikrocontroller mit der Entwicklungsumgebung zu verbinden.
\textbf{USB}-Debug-Kommunikation, die eine einfache Fehlersuche und Überwachung ermöglicht.
Lötpads für \textbf{GPIO-Anschlüsse}, um externe Komponenten flexibel verbinden zu können.\\
Diese Schaltung blieb über die gesamte Entwicklungsphase unverändert, da das Design von Anfang an stabil und zuverlässig lief.
\begin{figure}[ht]
\begin{center}

\caption{Designphasen}
\label{mcuevl}
\end{center}
\end{figure}
\paragraph{Motor Treiber}
Die Aufgabe des Motortreibers besteht in der Ansteuerung der drei BLDC-H-Brücken, der Phasenstrommessung für den Sinusbetrieb und der Drehmomentregelung. Die erste Version des Motortreibers basierte auf dem TI DRV8302 Treiber-IC, das aus dem VESC-Referenzdesign übernommen wurde. Dieses IC bot mehrere Vorteile: Integrierte \textbf{Spannungsversorgung} 12-60V. \textbf{Integrierte Verstärker} für die Phasenstrommessung. \textbf{Fehlererkennung} für Bootstrap-Spannung, Phasenstrom und Phasenspannung über Integrierte SPI Kommunikation. Einfache Integration durch ein gut dokumentiertes Design.
\newpage
\paragraph{Netzteil}
Das Netzteil übernimmt die Aufgabe, aus der Akku-Spannung von ~42–58V (siehe Anhang Entwicklung \ref{stateofC}) alle systemrelevanten Spannungen zu erzeugen:
12V (min. 1A): Versorgung von Beleuchtung, Lüftern und Relais.
5V (min. 0.5A): Stromquelle für das Display und die Motorsensoren.
3.3V (min. 0.3A): Energieversorgung für den Mikrocontroller und weitere logische Komponenten.\\
In der ersten Version des Netzteils wurde ein DC/DC-Spannungsregler für 12V und LDOs (Low-Dropout-Regler) für 5V und 3.3V verwendet. Die LDOs schienen aufgrund des geringen Beschaltungsaufwand eine kostengünstige Lösung zu sein.
Allerdings zeigten die Tests, dass der Spannungsabfall auf dem 5V-LDO zu hoch war, um die notwendige Leistung zuverlässig bereitzustellen. Dies führte zu einer Überarbeitung des Designs in Designphase 2.
\section{Designphase 2}
\paragraph{Integration}
Für die ersten Inbetriebnahmen wurde ein vereinfachter Testaufbau konzipiert, um die Funktion der einzelnen Baugruppen zu verifizieren und Schwachstellen im Design frühzeitig zu identifizieren.\\
Zur Sicherstellung des Personenschutzes kamen ein Labornetzteil mit Überstromschutz sowie ein kleiner, leistungsschwacher 50W NEMA-Motor zum Einsatz. Das Labornetzteil reduziert das Risiko elektrischer Fehler im Vergleich zur direkten Nutzung eines Akkus. Zudem minimiert der nur 300 g leichte Motor die Gefahren durch rotierende mechanische Teile im Vergleich zum deutlich leistungsstärkeren 36-Zoll-Hub-Motor.
\begin{figure}[ht]
\begin{center}

\caption{Testaufbau Blockdiagramm}
\label{labtest}
\end{center}
\end{figure}
\newpage
\paragraph{Motor Treiber Redesign}
Trotz der Vorteile wurde der TI DRV8302 nicht für die finale Version verwendet, hauptsächlich aus folgenden Gründen: Hohe Kosten des Treiber-ICs (ca. 8 € pro Stück bei Distributoren wie Digikey).
Der Wunsch, das Design stärker von der Referenzlösung abzuheben und eigene Entwicklungen einzubringen.\\
In der zweiten Version wurde der Infineon IR2101S eingesetzt, ein Halbbrückenregler, der zu einem Bruchteil der Kosten (unter 1 €) erhältlich ist. Für die Phasenstrommessung war eine zusätzliche Verstärkerschaltung erforderlich, die mithilfe des AD8418 realisiert wurde. Dieses Design ermöglichte eine deutlich günstigere und individuellere Umsetzung.
\paragraph{Netzteil Redesign}
in der zweiten Version wurde der 5V-LDO durch einen weiteren DC/DC-Wandler ersetzt, um dessen Verluste zu minimieren. Hier für wurde ein neuer DC/DC-Wandler(LMR36520) mit variabler Ausgangsspannung eingeführt, um die selben Komponenten für 12V \& 5V Versorgung zu nutzen.
\section{Designphase 3}
Nachdem die grundlegenden Funktionen Gestalt angenommen hatten, konnten nun die Zusatzfunktionen in den Fokus genommen werden.
\paragraph{Display}
Für die Anbindung von Display-Modulen wurde eine spezielle bidirektionale Level-Shifter-Schaltung entwickelt (siehe Schaltplan Abbildung \ref{shifter}). Ziel war es, eine Schnittstelle zu schaffen, die das breite Angebot an Arduino-, ESP32- und Raspberry Pi-Displays voll ausnutzen kann. Dafür musste sowohl UART als auch I2C mit 3.3V- und 5V-Logik-Level unterstützt werden.\\
Es ist wichtig zu erwähnen, dass die verbaute Schaltung die Übertragungsrate auf die Schaltfrequenz des 2N7002-MOSFETs limitiert. Diese liegt mit rund 250 kHz jedoch weit über den benötigten 10–100 kHz (I2C Normal/Fast Speed) bzw. 9,6–115,2 kBaud (UART), die für herkömmliche Display-Module erforderlich sind. Das im finalen Design verwendete 2004 LCD benötigt lediglich 10 kHz I2C, sodass die gewählte Schaltung mehr als ausreichend ist.
\paragraph{LED Treiber}
Für die Steuerung der Beleuchtung war lediglich eine einfache MOSFET-Treiber-Schaltung erforderlich (siehe Schaltplan Abbildung \ref{blinker}). Diese konnte problemlos auf einer Lochrasterplatine evaluiert werden und ermöglicht die Ansteuerung gängiger 12V-Fahrrad- und Motorradbeleuchtungselemente.\\
Die gleiche Schaltung wurde zudem für den Betrieb der Lüfter sowie des Selbsthaltere­lais verwendet. Hier war lediglich die Ergänzung einer Freilaufdiode erforderlich, um Spannungsspitzen beim Schalten der induktiven Lasten zu vermeiden.
\newpage
\section{Abschluss der Entwicklung}
Nach der Fertigstellung der finalen Designs der einzelnen Funktionsgruppen wurde eine Gesamthardware entwickelt, die alle Komponenten nahtlos miteinander verbindet. Diese schrittweise Integration erwies sich als äußerst effizient, da sie mehrere Vorteile bot:\\
\textbf{Kostenersparnis:} Durch die Iteration auf kleinen, kostengünstigen 2-Layer-PCBs, die weniger Bestückungsaufwand erforderten.\\
\textbf{Zeitersparnis:} Die Integration basierte auf stabilen und getesteten Funktionsgruppen, wodurch bereits fertige Layouts einfach miteinander verbunden werden konnten.\\
\textbf{Erhöhte Zuverlässigkeit:} Potenzielle Fehlerquellen wurden bereits in der zweiten Designphase identifiziert und behoben, was die Robustheit der Gesamthardware deutlich verbesserte.\\
Die erfolgreiche Integration aller Funktionsgruppen in eine einzige, optimierte Hardware stellte somit einen entscheidenden Meilenstein in der Realisierung des Projekts dar.

\chapter{Relevante Konzepte}
\section{BLDC}
\paragraph{Grundlagen}
Ein BLDC-Motor (bürstenloser Gleichstrommotor) funktioniert durch ein rotierendes Magnetfeld, das von Spulen im Stator erzeugt wird. Der Rotor mit Permanentmagneten wird von diesem Magnetfeld angezogen und in Drehung versetzt.\\
\begin{figure}[ht]
\begin{center}

\caption{(Texas Instruments. (2015). Trapezoidal Control of BLDC Motors Using Hall Effect Sensors . C2000 Systems and Applications Team, Bilal Akin, Manish Bhardwaj, \& Jon Warriner.)}
\label{motor}
\end{center}
\end{figure}

Zur Synchronisation des elektrischen Stroms mit der Position des Rotors verwenden BLDC-Motoren häufig Hallsensoren oder andere Positionssensoren.
Diese Sensoren ermitteln die exakte Position des Rotors und geben diese Information an den Controller weiter, sodass die Spulen präzise im richtigen Moment angesteuert werden. Diese Sensorik machen einen der erheblichen vorteile von modernen BLDC motoren gegenüber herkömmlichen Wechselstrom motoren aus. 
\newpage
\paragraph{Ansteuerung}
Die Steuerung von BLDC-Motoren (Brushless DC-Motoren) ist ein zentraler Aspekt ihrer Anwendung und bestimmt maßgeblich die Effizienz, Laufruhe und Steuerbarkeit der Motoren. In diesem Kapitel werden die wichtigsten Steuerungsmethoden für BLDC-Motoren beschrieben: Sinussteuerung, FOC-Steuerung und Trapezsteuerung.
\paragraph{Trapez Steuerung} ist eine einfachere und kostengünstigere Methode zur Steuerung von BLDC-Motoren. Sie verwendet rechteckige (trapezförmige) Spannungs- oder Stromwellen, um die Phasen des Motors zu betreiben.\textbf{Funktionsweise:}
Der Rotor wird durch das Erzeugen eines trapezförmigen Magnetfelds angetrieben. Die Kommutierung erfolgt diskret in Schritten von 60° elektrischem Winkel. Die Rotorposition wird meist mithilfe von Hall-Sensoren erfasst. \textbf{Vorteile:}
Einfache Umsetzung, Hohes Drehmoment, Geringste Schaltverluste,
\textbf{Nachteile:} Höhere Geräusch- und Vibrationsentwicklung im Vergleich zu Sinus- oder FOC-Steuerung. Weniger effizient, besonders bei hoher Drehzahl.
\begin{figure}[ht]
\begin{center}

\caption{(Texas Instruments. (2015). Trapezoidal Control of BLDC Motors Using Hall Effect Sensors . C2000 Systems and Applications Team, Bilal Akin, Manish Bhardwaj, \& Jon Warriner.)}
\label{trap}
\end{center}
\end{figure}
\paragraph{Sinus Steuerung} basiert darauf, die Ströme in den Phasen des Motors so zu regeln, dass sie sinusförmig verlaufen. Dadurch wird ein gleichmäßiges Drehmoment erzeugt, was sich in einer hohen Laufruhe und geringen Vibrationen äußert. \textbf{Funktionsweise:}
Die Sinussteuerung verwendet Sinuswellen als Referenzsignal für die Phasenströme. Diese werden über Pulsweitenmodulation (PWM) in die Wicklungen eingespeist. \textbf{Vorteile:} Sehr leiser und vibrationsarmer Betrieb. Bessere Effizienz bei hohen Drehzahlen. Geeignet für Anwendungen, bei denen Laufruhe entscheidend ist. \textbf{Nachteile:} Erfordert komplexe Elektronik und präzise Sensorik zur Bestimmung der Rotorposition. Kann weniger effizient sein als andere Methoden bei hoher Last im unteren Drehzahl-Bereich.
\paragraph{FOC Steuerung} Field-Oriented Control (Vektorregelung) ist eine fortschrittliche Methode zur Steuerung von BLDC-Motoren. Sie nutzt mathematische Transformationen, um die Drehmoment- und Magnetisierungsströme unabhängig voneinander zu regeln. \textbf{Funktionsweise:} Die Rotorposition wird kontinuierlich überwacht, oft mithilfe von Hall-Sensoren oder Encodern. Mithilfe einer Park- und Clarke-Transformation werden die Phasenströme von einem dreiphasigen in ein zweidimensionales Koordinatensystem (d-q-Achsen) transformiert. Dies ermöglicht die gezielte Regelung des Drehmoments (q-Achse) und der Magnetisierung (d-Achse). \textbf{Vorteile:} Sehr hohe Effizienz bei variabler Drehzahl und Last. Präzise Steuerung des Drehmoments. Unterstützt hohe Drehzahlen und bietet bessere Leistung als andere Methoden. \textbf{Nachteile:} Hohe Rechenleistung erforderlich, da fortschrittliche Algorithmen verwendet werden. Aufwendige Sensorik und Kalibrierung notwendig.
\paragraph{}In diesem Projekt wurde die Trapezsteuerung als Steuerungsmethode ausgewählt. Ausschlaggebend hierfür waren die einfache Implementierung, das hohe Drehmoment und die vorhandene Sensorik des Fahrradmotors, der nur eine Auflösung von 60° bietet. Die Hardware des Systems ist jedoch vollständig ausgestattet, um auch eine Sinussteuerung zu realisieren. Eine Umsetzung der FOC-Steuerung ist hingegen mit dem aktuellen Motor nicht möglich, da hierfür entweder präzisere Hall-Sensoren oder eine Back-EMF-Messschaltung erforderlich wären.
\part{Anhang}

\chapter{System Design}
\textbf{System Komponenten:}\\
\\
\begin{tabular}[h]{l|c|r}
\label{SysKomp}
\textbf{Bauteil} & \textbf{Name} & \textbf{Beschreibung} \\
\hline
Motor & Viribus LY23048911 & 1KW BLDC Motor \\
\hline
Akku & Unit Pack S039-3 & 48V 15Ah 750W/h\\
\hline
Display & GeeekPi I2C 2004 LCD & 20x4 LCD I²C display\\
\hline
 & QWork WD7435 & Lenkerschalter-Beleucht\\  
Bedienelemte & Greluma ZL277LUM & Lenker E-Stop Schalter\\
 & VGEBY B08KFC114S & Analog Gasgriff\\
 \hline
Scheinwerfer & Filmer 49002 & Fahrad Scheinwerfer\\
\hline
Rücklicht & evermotor A08051-3 & Motorrad 50mm Brems-Rücklicht\\
\hline
Blinker & Dowrap B0CK6ZTGS3 & 12V Led blinker Vorne\\
 & evermotor A08023 & 12V Led blinker Hinten\\
\hline
Steuergerät & RESC\_V2 & 13-64V 30A E-Bike Steuergerät\\
\hline
Notaus & Tawvelm SPST & 48V 100A DC Schalter\\
\hline
Lüfter & 2x GDA4010 & 40x10mm 12V Lüfter\\
\hline
Kühlkörper & VPR138/94-M3 & 94x46x33mm Kühlkörper\\
\end{tabular}

\begin{figure}[ht]
\begin{center}

\caption{Vereinfachtes System Diagramm}
\label{EBike_sys}
\end{center}
\end{figure}

\chapter{Entwicklung}
\begin{figure}[ht]
\begin{center}

\caption{48V Akku Spannungskurve}
\label{stateofC}
\end{center}
\end{figure}

\chapter{Schaltplan}
\includepdf[angle=90,pages={1-7}]{PDF/RESC_V2 Schematic.pdf}

\chapter{Layout}
\includepdf[angle=90,pages={1-9}]{PDF/RESC_V2 PCB.pdf}
\chapter{BOM}
\includepdf[pages={1-6}]{PDF/RESC_V2 BOM.pdf}

\chapter{Source Code}
\section{Main.c/h}
\begin{lstlisting}[language=C, caption=\textbf{Private Defines},label={define}, mathescape=true, breaklines=true]
/* USER CODE BEGIN Private defines */
//Machine States
#define READY 0
#define DRIVE 1
#define BREAK 2
#define SWFAULT 3
#define HWFAULT 4
#define DEBUGST 6
//BLDC
#define THROTTLE_THRESHOLD 30 //Threshold for initial start to prevent adc drift
#define MAXDUTY 100		//Motor PWM Duty Cycle
#define MINDUTY 0		//Motor PWM Duty Cycle
#define MAXADC 3170		//throttle MAX 2,55V
#define MINADC 1055		//throttle MIN 0.85V
#define MAXRPM 4500		//Max RPM of the given motor
#define MINRPM 25		//Min RPM of the given motor
//Software limits for ADC measurments
#define SW_OC 28	//Over Current		28A
#define SW_UV 44	//Under Voltage		44V
#define SW_OV 60	//Over Voltage 		60V
#define SW_OT 100	//Over Temperature 	100C
#define Temp_FAN_ON  80	//Turn on fan here	80C
#define Temp_FAN_OFF 60	//Turn off fan here 60C
//Blinker PWM
#define BLINKER_START 250 // Run blinker at nom. PWM
#define BLINKER_STOP 500  // Turns off blinker PWM
//other
#define ADC_TIMEOUT 20
#define SWFAULT_TIMOUT 300
/* USER CODE END Private defines */
\end{lstlisting}
Die Benutzerdefiniert-Konstanten dienen der Konfiguration von Grenzwerten und Betriebsparametern. Änderungen sind zentral und einfach möglich.
\newpage
\begin{lstlisting}[language=C, caption=\textbf{Main Loop},label={main}, mathescape=true, breaklines=true]
  /* USER CODE BEGIN WHILE */
  while (1)
  {
	  //Read inputs
	  readADCs();
	  readDI();
	  doADCs();
	  /* STATE MACHINE */
	  switch(STATE){
	  	  case READY:
	  		  ready();
	  		  setDO();
	  		  break;
	  	  case DRIVE:
	  		  drive();
	  		  setDO();
	  		  break;
	  	  case BREAK:
	  		  breaking();
	  		  setDO();
	  		  break;
	  	  case SWFAULT:
	  		  resetDO();
	  		  swfault();
	  		  break;
	  	  case HWFAULT:
	  		  resetDO();
	  		  hwfault();
	  		  break;
	  	  case DEBUGST:
	  		  debug();
	  		  setDO();
	  		  break;
	  	  default:
	  		  resetDO();
	  		  hwfault();
	  		  break;
	  	  }
	  //Update LCD every 500ms
	  if(timcc>=5){
		  update_lcd_val(&lcd_val,ADC_VAL);
		  writeState();
		  timcc =0;
	  }
	  HAL_Delay(25);
    /* USER CODE END WHILE */
  }
\end{lstlisting}
Die Endlosschleife (while (1)) ist der zentrale Ablauf des Programms und führt kontinuierlich die Eingabelesung, Zustandsmaschine und die Anzeigeaktualisierung aus.
\newpage
\begin{lstlisting}[language=C, caption=\textbf{void readADCs()},label={readADC}, mathescape=true, breaklines=true]
/**
  * @brief Reads ADC values for voltage, current, and temperature, and updates corresponding variables
  * @param None
  * @retval void
  */
void readADCs(){
	uint16_t a =0;  //Int dump for ADC
	float x = 0.0;
	//READ Voltage
	ADC3_Select_CH(0);
	HAL_ADC_Start(&hadc3);
	HAL_ADC_PollForConversion(&hadc3, ADC_TIMEOUT);
	a =HAL_ADC_GetValue(&hadc3);
	HAL_ADC_Stop(&hadc3);
	x = adc_volt(a);
	ADC_VAL[0] = 0.15 * x + (1.0- 0.05)*ADC_VAL[0];

	//READ Current
	ADC3_Select_CH(1);
	HAL_ADC_Start(&hadc3);
	HAL_ADC_PollForConversion(&hadc3, ADC_TIMEOUT);
	a =HAL_ADC_GetValue(&hadc3);
	HAL_ADC_Stop(&hadc3);
	x = adc_volt(a);
	ADC_VAL[1] = 0.15 * x + (1.0- 0.05)*ADC_VAL[1];

	//READ Temperature
	ADC3_Select_CH(2);
	HAL_ADC_Start(&hadc3);
	HAL_ADC_PollForConversion(&hadc3, ADC_TIMEOUT);
	a =HAL_ADC_GetValue(&hadc3);
	HAL_ADC_Stop(&hadc3);
	x = adc_volt(a);
	ADC_VAL[2] = 0.15 * x + (1.0- 0.05)*ADC_VAL[2];

}
\end{lstlisting}
\newpage
\begin{lstlisting}[language=C, caption=\textbf{void doADCs()},label={doADC}, mathescape=true, breaklines=true]
/**
  * @brief Processes ADC values to monitor and control system states, including fault detection and fan control
  * @param None
  * @retval void
  */
void doADCs() {
    // Ensure ADC_VAL array has enough elements
    if (sizeof(ADC_VAL) / sizeof(ADC_VAL[0]) < 3) {
        // Handle error (e.g., log it, set state to fault)
        STATE = SWFAULT;
        HD44780_SetCursor(0, 1);
        HD44780_PrintStr("ERR:ADC VAL SIZE");
        return;
    }
    // Release SW_FAULT if all conditions are normal
    if (STATE == SWFAULT) {
        if (ADC_VAL[0] < SW_OV && ADC_VAL[0] > SW_UV + 2 &&  // Voltage OK
            ADC_VAL[1] <= 1 &&                              // Current OK
            ADC_VAL[2] <= Temp_FAN_ON) {                    // Temperature OK
            STATE = BREAK;
        }
    }
    // Device is in normal condition
    if (STATE !=SWFAULT){
        // Control the fan based on temperature
        if (ADC_VAL[2] >= Temp_FAN_ON) {
            HAL_GPIO_WritePin(GPIOB, PB8_DO_FAN_Pin, GPIO_PIN_RESET); // FAN ON
        } else if (ADC_VAL[2] <= Temp_FAN_OFF) {
            HAL_GPIO_WritePin(GPIOB, PB8_DO_FAN_Pin, GPIO_PIN_SET);   // FAN OFF
        }
        // Check for software faults and set error messages
        if (ADC_VAL[0] >= SW_OV) {
            setFaultState("ERR:SW OV");
        } else if (ADC_VAL[0] <= SW_UV) {
            setFaultState("ERR:SW UV");
        } else if (ADC_VAL[1] >= SW_OC) {
            setFaultState("ERR:SW OC");
        } else if (ADC_VAL[2] >= SW_OT) {
            setFaultState("ERR:SW OT");
        }
    }
}
\end{lstlisting}
\newpage
\begin{lstlisting}[language=C, caption=\textbf{void readDI()},label={readDI}, mathescape=true, breaklines=true]
/**
  * @brief Reads digital input values from GPIO pins and updates button states
  * @param None
  * @retval void
  */
void readDI(){
    // Button data[Light, Blinker L, Blinker R, Aux]
    uint16_t but_new[4];
    but_new[0] = (GPIOC->IDR & GPIO_IDR_ID10) ? 0x0001 : 0x0000;
    but_new[1] = (GPIOC->IDR & GPIO_IDR_ID11) ? 0x0001 : 0x0000;
    but_new[2] = (GPIOC->IDR & GPIO_IDR_ID12) ? 0x0001 : 0x0000;
    but_new[3] = (GPIOC->IDR & GPIO_IDR_ID13) ? 0x0001 : 0x0000;

    for (int i = 0; i < 4; i++) {
    	but[i] = but_new[i];
        }
}
\end{lstlisting}
\newpage
\begin{lstlisting}[language=C, caption=\textbf{void setDO()},label={setDO}, mathescape=true, breaklines=true]
/**
  * @brief Sets digital output states based on button inputs and updates system behavior accordingly
  * @param None
  * @retval void
  */
void setDO() {
	//Data error
	if (sizeof(but) / sizeof(but[0]) < 4) {
		setFaultState("ERR: DO SIZE");
	}

    // Button data: [Light, Blinker L, Blinker R, Aux]
    // Toggle lights based on button state
    HAL_GPIO_WritePin(GPIOB, PB3_DO_LIGHT_Pin, but[0] == 0 ? GPIO_PIN_RESET : GPIO_PIN_SET);

    // Handle Blinker Left (PWM Control)
    if (but[1] == 1) {
        TIM3->CCR2 = BLINKER_START;  // Start PWM
    } else {
        TIM3->CCR2 = BLINKER_STOP;  // Stop PWM
    }

    // Handle Blinker Right (PWM Control)
    if (but[2] == 1) {
        TIM3->CCR1 = BLINKER_START;  // Start PWM
    } else {
        TIM3->CCR1 = BLINKER_STOP;  // Stop PWM
    }

    // Handle Aux button action
    if (but[3] == 0) {
        HAL_GPIO_TogglePin(PB1_LED_RED_GPIO_Port, PB1_LED_RED_Pin); // Toggle LED
        STATE = DRIVE;                                             // Set state to DRIVE
    }
}
\end{lstlisting}
\newpage
\begin{lstlisting}[language=C, caption=\textbf{void ready()},label={ready}, mathescape=true, breaklines=true]
/**
  * @brief Prepares the system for motor operation by initializing throttle input and PWM control
  * @param None
  * @retval void
  */
void ready() {
    // Start ADC conversion
    HAL_ADC_Start(&hadc1);
    HAL_ADC_PollForConversion(&hadc1, 20);

    // Get throttle raw value
    rawThrot = HAL_ADC_GetValue(&hadc1);

    // Map throttle value to duty cycle range
    int THrotduty = map(rawThrot, MINADC, MAXADC, MINDUTY, MAXDUTY);

    // Check if throttle duty cycle exceeds the threshold
    if (THrotduty >= THROTTLE_THRESHOLD) {
        // Initialize PWM outputs to zero
        TIM1->CCR1 = 0;
        TIM1->CCR2 = 0;
        TIM1->CCR3 = 0;

        // Start PWM for all three channels
        HAL_TIM_PWM_Start(&htim1, TIM_CHANNEL_1);
        HAL_TIM_PWM_Start(&htim1, TIM_CHANNEL_2);
        HAL_TIM_PWM_Start(&htim1, TIM_CHANNEL_3);

        // Initialize BLDC motor
        initBLDC();

        // Set initial duty cycle
        duty = 10; // Set initial duty cycle; modify as needed

        // Change state to DRIVE
        STATE = DRIVE;
    }
}
\end{lstlisting}
\newpage
\begin{lstlisting}[language=C, caption=\textbf{void drive()},label={drive}, mathescape=true, breaklines=true]
/**
  * @brief Controls the motor drive by reading throttle input and updating the PWM duty cycle
  * @param None
  * @retval void
  */
void drive() {
    // Start ADC conversion
    HAL_ADC_Start(&hadc1);

    // Wait for ADC conversion to complete with a timeout
    if (HAL_ADC_PollForConversion(&hadc1, ADC_TIMEOUT) == HAL_OK) {
        // Get raw throttle value
        rawThrot = HAL_ADC_GetValue(&hadc1);

        // Map the raw throttle value to a duty cycle range
        int THrotduty = map(rawThrot, MINADC, MAXADC, MINDUTY, MAXDUTY);

        // Update the duty cycle
        duty = THrotduty;
    } else {
        // Handle ADC conversion error (optional)
        duty = 0; // Set duty to a safe value in case of failure
        setFaultState("ERR: ADC");
        // Optionally log or display an error message
    }
}
\end{lstlisting}
\begin{lstlisting}[language=C, caption=\textbf{void breaking()},label={break}, mathescape=true, breaklines=true]
/**
  * @brief Engages the braking mechanism by stopping PWM outputs and activating braking GPIO pins
  * @param None
  * @retval void
  */
void breaking() {
    // Stop all PWM channels
    TIM1->CCR1 = 0;
    TIM1->CCR2 = 0;
    TIM1->CCR3 = 0;
    duty = 0; // Reset duty cycle to zero

    HAL_TIM_PWM_Stop(&htim1, TIM_CHANNEL_1);
    HAL_TIM_PWM_Stop(&htim1, TIM_CHANNEL_2);
    HAL_TIM_PWM_Stop(&htim1, TIM_CHANNEL_3);

    // Set GPIO pins for braking mode
    HAL_GPIO_WritePin(GPIOB, PB13_U_Pin, GPIO_PIN_SET);
    HAL_GPIO_WritePin(GPIOB, PB14_V_Pin, GPIO_PIN_SET);
    HAL_GPIO_WritePin(GPIOB, PB15_W_Pin, GPIO_PIN_SET);
}
\end{lstlisting}
\newpage
\begin{lstlisting}[language=C, caption=\textbf{void swfault()},label={swfault}, mathescape=true, breaklines=true]
/**
  * @brief Handles the software fault state by engaging braking and transitioning to HWFAULT after a timeout
  * @param None
  * @retval void
  */
void swfault() {
    // Perform breaking to ensure the system is in a safe state
    breaking();

    // Check if the timeout for SWFAULT has elapsed (30s = 300 units of 100ms)
    if (swfault_time_counter >= SWFAULT_TIMOUT) {
        // Transition to HWFAULT state
        STATE = HWFAULT;
    }
}
\end{lstlisting}
\begin{lstlisting}[language=C, caption=\textbf{void hwfault()},label={hwfault}, mathescape=true, breaklines=true]
/**
  * @brief Handles hardware faults by engaging braking, displaying an error message, and halting execution
  * @param None
  * @retval void
  */
void hwfault(){
	STATE = HWFAULT;
	breaking();
	HD44780_SetCursor(0,1);
	HD44780_PrintStr("ERROR:HW FAULT");
	//Stuck untill Power on reset
	while(1){
		HAL_Delay(100);

	}
}
\end{lstlisting}
\newpage
\begin{lstlisting}[language=C, caption=\textbf{void HAL\_GPIO\_EXTI\_Callback(uint16\_t GPIO\_Pin)},label={interrupt}, mathescape=true, breaklines=true]
//Interrupt Pin Function
void HAL_GPIO_EXTI_Callback(uint16_t GPIO_Pin) {
    // Handle Break Signal Interrupt
    if (GPIO_Pin == EXTI5_Break_Pin) {
    	handleBreakInterrupt();
    }
    // Handle Hardware Fault Interrupt
    else if (GPIO_Pin == EXTI9_FAULT_Pin) {
    	handleHardwareFaultInterrupt();
    }
    // Handle Hall Sensor Interrupt
    else if (STATE == DRIVE || STATE == READY) {
        if (GPIO_Pin == EXTI6_HALL_U_Pin || GPIO_Pin == EXTI7_HALL_V_Pin || GPIO_Pin == EXTI8_HALL_W_Pin) {
        	handleHallSensorInterrupt(GPIO_Pin);
        }
    } else {
        // No operation for other states
        __NOP();
    }
}
\end{lstlisting}
\begin{lstlisting}[language=C, caption=\textbf{void handleHardwareFaultInterrupt()},label={hwint}, mathescape=true, breaklines=true]
/**
  * @brief Handles hardware fault interrupts, transitioning motor state to HWFAULT
  * @param None
  * @retval void
  */
void handleHardwareFaultInterrupt() {
	STATE = HWFAULT;
    // Optional: Identify Fault Reason and shutdown Device
    // Example readADCs() and determine fault cause;
}
\end{lstlisting}
\newpage
\begin{lstlisting}[language=C, caption=\textbf{void handleBreakInterrupt()},label={brint}, mathescape=true, breaklines=true]
/**
  * @brief Handles the brake interrupt signal, transitioning motor state between BREAK and READY
  * @param None
  * @retval void
  */
void handleBreakInterrupt() {
    uint16_t breakSignal = (GPIOC->IDR & GPIO_IDR_ID5) ? 0x0001 : 0x0000;
    if (breakSignal == 0) {
        // Transition to BREAK state
        STATE = BREAK;
        HAL_GPIO_WritePin(PB0_LED_GREEN_GPIO_Port, PB0_LED_GREEN_Pin, GPIO_PIN_RESET);
        HAL_GPIO_WritePin(PB1_LED_RED_GPIO_Port, PB1_LED_RED_Pin, GPIO_PIN_SET);
    } else {
        // Transition to READY state if motor is fully stopped
    	if(rpm >=5){
    		STATE = DRIVE;
    	}else{
    		STATE = READY;
    	}
        HAL_GPIO_WritePin(PB0_LED_GREEN_GPIO_Port, PB0_LED_GREEN_Pin, GPIO_PIN_SET);
        HAL_GPIO_WritePin(PB1_LED_RED_GPIO_Port, PB1_LED_RED_Pin, GPIO_PIN_RESET);
    }
}
\end{lstlisting}
\newpage
\begin{lstlisting}[language=C, caption=\textbf{void handleHallSensorInterrupt(uint16\_t GPIO\_Pin)},label={senint}, mathescape=true, breaklines=true]
/**
  * @brief Handles hall sensor interrupts, updates commutator step for motor control
  * @param GPIO_Pin      = Pin number that triggered the interrupt
  * @retval void
  */
void handleHallSensorInterrupt(uint16_t GPIO_Pin) {
    hallCC++; // Increment hall sensor counter

    // Read hall sensor states
    uint16_t hall[3];
    hall[0] = (GPIOC->IDR & GPIO_IDR_ID6) ? 0x0001 : 0x0000; // Sensor U
    hall[1] = (GPIOC->IDR & GPIO_IDR_ID7) ? 0x0001 : 0x0000; // Sensor V
    hall[2] = (GPIOC->IDR & GPIO_IDR_ID8) ? 0x0001 : 0x0000; // Sensor W

    // Trapazoidal control
    uint16_t commutatorStep = hallState(hall);
    commutator(commutatorStep, duty, dir);

    // Optional: Implement sine control as needed
    /*
     * uint16_t commutatorStep = hallState(hall);
     * uint16_t phaseAngle = electricalAngle(commutatorStep);
     * FOCcommutator(phaseAngle, duty);
     */
}

\end{lstlisting}

\newpage
\section{BLDC.c/h}
\begin{lstlisting}[language=C, caption=\textbf{uint16\_t hallState(uint16\_t hall[])},label={hallS}, mathescape=true, breaklines=true]
/**
  * @brief Takes hallsensor states and determines the commutator position
  * @param hall[] 		= arry containing the values read from the 3 Hall Sensors
  * @retval			= The Communator step between 0-5 used to set BLDC gates
  * Hall Sensor State	Rotor Position	Electrical Angle (Degrees)
  *				001		0 - 60			0 - 1440
  *				101		60 - 120		1440 - 2880
  *				100		120 - 180		2880 - 4320
  *				110		180 - 240		4320 - 5760
  *				010		240 - 300		5760 - 7200
  *				011		300 - 360		7200 - 8640
  *
  */
uint16_t hallState(uint16_t hall[]){

	uint16_t commutatorState = -1;
	  if ((hall[0] == 1) && (hall[1] == 0) && (hall[2] == 1)) {
		//Mechanical Angle 0-60
		  commutatorState = 0;
	  }
	  else if  ((hall[0] == 0) && (hall[1] == 0) && (hall[2] == 1)) {
		//Mechanical Angle 60-120
		  commutatorState = 1;
	  }
	  else if  ((hall[0] == 0) && (hall[1] == 1) && (hall[2] == 1)) {
		//Mechanical Angle 120-180
		  commutatorState = 2;
	  }
	  else if  ((hall[0] == 0) && (hall[1] == 1) && (hall[2] == 0)) {
		//Mechanical Angle 180-240
		  commutatorState = 3;
	  }
	  else if  ((hall[0] == 1) && (hall[1] == 1) && (hall[2] == 0)) {
		//Mechanical Angle 240-300
		  commutatorState = 4;
	  }
	  else if  ((hall[0] == 1) && (hall[1] == 0) && (hall[2] == 0)) {
		//Mechanical Angle 300-360
		  commutatorState = 5;
	  }
	  return commutatorState;
}
\end{lstlisting}
\newpage
\begin{lstlisting}[language=C, caption=\textbf{void commutator(int commutatorStep, int duty, int dir)},label={commuta}, mathescape=true, breaklines=true]
/**
  * @brief Sets Three Phase gate driver according to commutator position
  * @param commutatorStep 		= 0-5 determined by FOC hall sensor position
  * @param duty					= PWM duty cycle 0-100
  * @param dir					= motor direction: 1 = fwr; -1= rws
  * @retval			= void
  */
void commutator(int commutatorStep, int duty, int dir){

	if(dir ==1){
		switch(commutatorStep){

		//U PWM
		//Hall state: 		U = HIGH	V = LOW		W = HIGH
		//Phase Current:	U = I		V =	-I		W = 0
		//High Side			U = PWM		V = OFF		W = OFF
		//Low Side			U = OFF		V = ON		W = OFF
		case 0:
			//Low Side
			HAL_GPIO_WritePin(GPIOB,PB13_U_Pin,GPIO_PIN_RESET);
			HAL_GPIO_WritePin(GPIOB,PB14_V_Pin,GPIO_PIN_SET);
			HAL_GPIO_WritePin(GPIOB,PB15_W_Pin,GPIO_PIN_RESET);
			//High Side
			TIM1->CCR1 = duty;
			TIM1->CCR2 = 0;
			TIM1->CCR3 = 0;

			break;

		//W PWM
		//Hall state: 		U = LOW		V = LOW		W = HIGH
		//Phase Current:	U = 0		V =	-I		W = I
		//High Side			U = OFF		V = OFF		W = PWM
		//Low Side			U = OFF		V = ON		W = OFF
		case 1:
			//Low Side
			HAL_GPIO_WritePin(GPIOB,PB13_U_Pin,GPIO_PIN_RESET);
			HAL_GPIO_WritePin(GPIOB,PB14_V_Pin,GPIO_PIN_SET);
			HAL_GPIO_WritePin(GPIOB,PB15_W_Pin,GPIO_PIN_RESET);
			//High Side
			TIM1->CCR1 = 0;
			TIM1->CCR2 = 0;
			TIM1->CCR3 = duty;

			break;

		//W PWM
		//Hall state: 		U = LOW		V = HIGH	W = HIGH
		//Phase Current:	U = -I		V =	0		W = I
		//High Side			U = OFF		V = OFF		W = PWM
		//Low Side			U = ON		V = OFF		W = OFF
		case 2:
			//Low Side
			HAL_GPIO_WritePin(GPIOB,PB13_U_Pin,GPIO_PIN_SET);
			HAL_GPIO_WritePin(GPIOB,PB14_V_Pin,GPIO_PIN_RESET);
			HAL_GPIO_WritePin(GPIOB,PB15_W_Pin,GPIO_PIN_RESET);
			//High Side
			TIM1->CCR1 = 0;
			TIM1->CCR2 = 0;
			TIM1->CCR3 = duty;

			break;

		//V PWM
		//Hall state: 		U = LOW		V = HIGH	W = LOW
		//Phase Current:	U = -I		V =	I		W = 0
		//High Side			U = OFF		V = PWM		W = OFF
		//Low Side			U = ON		V = OFF		W = OFF
		case 3:
			//Low Side
			HAL_GPIO_WritePin(GPIOB,PB13_U_Pin,GPIO_PIN_SET);
			HAL_GPIO_WritePin(GPIOB,PB14_V_Pin,GPIO_PIN_RESET);
			HAL_GPIO_WritePin(GPIOB,PB15_W_Pin,GPIO_PIN_RESET);
			//High Side
			TIM1->CCR1 = 0;
			TIM1->CCR2 = duty;
			TIM1->CCR3 = 0;

			break;

		//V PWM
		//Hall state: 		U = HIGH; 	V = HIGH	W = LOW
		//Phase Current:	U = 0		V =	I		W = -I
		//High Side			U = OFF		V = PWM		W = OFF
		//Low Side			U = OFF		V = OFF		W = ON
		case 4:
			//Low Side
			HAL_GPIO_WritePin(GPIOB,PB13_U_Pin,GPIO_PIN_RESET);
			HAL_GPIO_WritePin(GPIOB,PB14_V_Pin,GPIO_PIN_RESET);
			HAL_GPIO_WritePin(GPIOB,PB15_W_Pin,GPIO_PIN_SET);
			//High Side
			TIM1->CCR1 = 0;
			TIM1->CCR2 = duty;
			TIM1->CCR3 = 0;

			break;

		//U PWM
		//Hall state: 		U = HIGH	V = LOW		W = LOW
		//Phase Current:	U = I		V =	0		W = -I
		//High Side			U = PWM		V = OFF		W = OFF
		//Low Side			U = OFF		V = OFF		W = ON
		case 5:
			//Low Side
			HAL_GPIO_WritePin(GPIOB,PB13_U_Pin,GPIO_PIN_RESET);
			HAL_GPIO_WritePin(GPIOB,PB14_V_Pin,GPIO_PIN_RESET);
			HAL_GPIO_WritePin(GPIOB,PB15_W_Pin,GPIO_PIN_SET);
			//High Side
			TIM1->CCR1 = duty;
			TIM1->CCR2 = 0;
			TIM1->CCR3 = 0;

			break;

		//i have no idea how you ended up here pls stop motor
		//High Side			U = OFF		V = OFF		W = OFF
		//Low Side			U = HIGH	V = HIGH	W = HIGH
		default:
			HAL_GPIO_WritePin(GPIOB,PB13_U_Pin,GPIO_PIN_SET);
			HAL_GPIO_WritePin(GPIOB,PB14_V_Pin,GPIO_PIN_SET);
			HAL_GPIO_WritePin(GPIOB,PB15_W_Pin,GPIO_PIN_SET);

			TIM1->CCR1 = 0;
			TIM1->CCR2 = 0;
			TIM1->CCR3 = 0;
			break;
		}
	}
	if(dir !=1){
		//no implimentation for reverse needed yet just break
		HAL_GPIO_WritePin(GPIOB,PB13_U_Pin,GPIO_PIN_SET);
		HAL_GPIO_WritePin(GPIOB,PB14_V_Pin,GPIO_PIN_SET);
		HAL_GPIO_WritePin(GPIOB,PB15_W_Pin,GPIO_PIN_SET);

		TIM1->CCR1 = 0;
		TIM1->CCR2 = 0;
		TIM1->CCR3 = 0;
	}
}
\end{lstlisting}
\newpage
\begin{lstlisting}[language=C, caption=\textbf{void initBLDC()},label={initBL}, mathescape=true, breaklines=true]
/**
  * @brief Initializes the BLDC motor by reading hall sensor values and setting the commutator step
  * @param None
  * @retval void
  */
void initBLDC(){
	uint16_t hall[3];
	hall[0]= (GPIOC->IDR & GPIO_IDR_ID6)? 0x0001 : 0x0000; // Sensor A
	hall[1]= (GPIOC->IDR & GPIO_IDR_ID7)? 0x0001 : 0x0000; // Sensor B
	hall[2]= (GPIOC->IDR & GPIO_IDR_ID8)? 0x0001 : 0x0000; // Sensor C

	int step= hallState(hall);
	commutator(step, 15,1);
}

\end{lstlisting}

\begin{lstlisting}[language=C, caption=\textbf{void BLDCbreak()},label={BLbreak}, mathescape=true, breaklines=true]
/**
  * @brief Engages the brake for the BLDC motor by setting all output phases high and stopping PWM signals
  * @param None
  * @retval void
  */
void BLDCbreak(){
	HAL_GPIO_WritePin(GPIOB,PB13_U_Pin,GPIO_PIN_SET);
	HAL_GPIO_WritePin(GPIOB,PB14_V_Pin,GPIO_PIN_SET);
	HAL_GPIO_WritePin(GPIOB,PB15_W_Pin,GPIO_PIN_SET);

	TIM1->CCR1 = 0;
	TIM1->CCR2 = 0;
	TIM1->CCR3 = 0;
}
\end{lstlisting}
\newpage
\section{liquidcrystal\_i2c.c/h}
\begin{lstlisting}[language=C, caption=\textbf{lcd struct},label={struct},mathescape=true, breaklines=true] 
/* lcd stuct */
typedef struct{
//Values for updating the display
  char volt[4] /*Storage DC Voltage */;
  char temp[3] /*Storage Drive temperature*/;
  char amp[4] /*Storage DC Current*/;
  char speed[2] /*Storage bike Speed*/;
  char erpm[4] /*Storage Motor rpm*/;
  char pwm[2] /*Storage PWM value*/;

//Cursor position for respective Values
  uint8_t cur_volt[2];
  uint8_t cur_temp[2];
  uint8_t cur_amp[2];
  uint8_t cur_speed[2];
  uint8_t cur_erpm[2];
  uint8_t cur_pwm[2];
} lcd_ar;
\end{lstlisting}

\begin{lstlisting}[language=C, caption=\textbf{void HD44780\_SetCursor(uint8\_t col, uint8\_t row)},label={setC}, mathescape=true, breaklines=true]
/**
  * @brief Sets the cursor position on the HD44780 LCD display
  * @param col    = Column position (0-based)
  * @param row    = Row position (0-based)
  * @retval void
  */
void HD44780_SetCursor(uint8_t col, uint8_t row)
{
  int row_offsets[] = { 0x00, 0x40, 0x14, 0x54 };
  if (row >= dpRows)
  {
    row = dpRows-1;
  }
  SendCommand(LCD_SETDDRAMADDR | (col + row_offsets[row]));
}
\end{lstlisting}

\begin{lstlisting}[language=C, caption=\textbf{void HD44780\_PrintStr(const char c[])},label={print}, mathescape=true, breaklines=true]
/**
  * @brief Prints a string to the HD44780 LCD display
  * @param c    = Pointer to a null-terminated string to display
  * @retval void
  */
void HD44780_PrintStr(const char c[])
{
  while(*c) SendChar(*c++);
}
\end{lstlisting}

\begin{lstlisting}[language=C, caption=\textbf{void Init\_lcd\_ar(lcd\_ar* lcd)},label={initLCD}, mathescape=true, breaklines=true]
/**
  * @brief Initializes the lcd_ar struct with default cursor positions and display values
  * @param lcd    = Pointer to an lcd_ar struct to initialize
  * @retval void
  */
void Init_lcd_ar(lcd_ar* lcd){
	//Load cursor positions
	lcd ->cur_volt[0] =15;
	lcd ->cur_volt[1] =0;

	lcd ->cur_temp[0]=0;
	lcd ->cur_temp[1]=0;

	lcd ->cur_amp[0] =15;
	lcd ->cur_amp[1] =1;

	lcd ->cur_speed[0]=9;
	lcd ->cur_speed[1]=3;

	lcd ->cur_erpm[0]=0;
	lcd ->cur_erpm[1]=3;

	lcd ->cur_pwm[0]=1;
	lcd ->cur_pwm[1]=2;

	//Set up Display for array mode
	//Init Volt
	HD44780_SetCursor(15,0);
	HD44780_PrintStr("42.0V");
	//Init Temp
	HD44780_SetCursor(0,0);
	HD44780_PrintStr("069C");
	//Init Current
	HD44780_SetCursor(15,1);
	HD44780_PrintStr("02.5A");
	//Init Speed
	HD44780_SetCursor(9,3);
	HD44780_PrintStr("10KM/H");
	//Init ERPM
	HD44780_SetCursor(0,3);
	HD44780_PrintStr("4000");
	//Iinit PWM
	//HD44780_SetCursor(1,2);
	//HD44780_PrintStr("00%");
}
\end{lstlisting}
\newpage
\begin{lstlisting}[language=C, caption=\textbf{void update\_lcd\_val(lcd\_ar* ar, float val[])},label={upLCD}, mathescape=true, breaklines=true]
/**
  * @brief Updates the lcd_ar struct and LCD display with new sensor values
  * @param ar     = Pointer to an lcd_ar struct containing cursor positions
  * @param val    = Array of float values to update [Voltage, Current, Temperature, Speed, (optional: PWM)]
  * @retval void
  */
void update_lcd_val(lcd_ar* ar, float val[]){
	//Set Voltage
	snprintf(ar->volt, 5, "%04.1f", val[0]);
	HD44780_SetCursor(ar->cur_volt[0],ar->cur_volt[1]);
	HD44780_PrintStr(ar->volt);
	//Set Current
	snprintf(ar->amp, 5, "%04.1f", val[1]);
	HD44780_SetCursor(ar->cur_amp[0],ar->cur_amp[1]);
	HD44780_PrintStr(ar->amp);
	//Set Temp
	snprintf(ar->temp, 4, "%03.0f", val[2]);
	HD44780_SetCursor(ar->cur_temp[0],ar->cur_temp[1]);
	HD44780_PrintStr(ar->temp);
	//Set Speed
	snprintf(ar->speed, 3, "%02.0f",val[3] );
	HD44780_SetCursor(ar->cur_speed[0],ar->cur_speed[1]);
	HD44780_PrintStr(ar->speed);
	//Set ERPM
	snprintf(ar->erpm, 5, "%04.0f",rpm);
	HD44780_SetCursor(ar->cur_erpm[0],ar->cur_erpm[1]);
	HD44780_PrintStr(ar->erpm);
	//Set PWm
	//snprintf(ar->pwm,3,"%02.0f",val[4] );
	//HD44780_SetCursor(ar->cur_pwm[0],ar->cur_pwm[1]);
	//HD44780_PrintStr(ar->pwm);

}
\end{lstlisting}
\newpage
\section{Mymath.c/h}
\begin{lstlisting}[language=C, caption=\textbf{pid struct},label={pid}, mathescape=true, breaklines=true]
typedef struct{
  float max /*! Max manipulated value */;
  float min /*! Miniumum manipulated value */;
  float e /*! Error value */;
  float i /*! Integrator value */;
  float kp /*! Proportional constant */;
  float ki /*! Integrator constant */;
  float kd /*! Differential constant */;
} pid_f_t;
\end{lstlisting}

\begin{lstlisting}[language=C, caption=\textbf{uint16\_t map()},label={map}, mathescape=true, breaklines=true]
/**
  * @brief Re-maps a number from one range to another
  * @param x 		= The number to map.
  * @param in_min	= The lower bound of the values current range.
  * @param in_max	= The upper bound of the values current range.
  * @param out_min	= The lower bound of the values target range.
  * @param out_max	= The upper bound of the values target range.
  * @retval			= The mapped value
  */
uint16_t map(uint16_t x, uint16_t in_min, uint16_t in_max, uint16_t out_min, uint16_t out_max) {
  return (x - in_min) * (out_max - out_min) / (in_max - in_min) + out_min;
}
\end{lstlisting}

\begin{lstlisting}[language=C, caption=\textbf{float adc\_volt(uint16\_t val)},label={adcV}, mathescape=true, breaklines=true]
/**
  * @brief Converts a raw ADC value to the corresponding input voltage
  * @param val    = Raw 12-bit ADC value (0-4095)
  * @retval float = Calculated input voltage
  */
float adc_volt(uint16_t val){
	//((val/(39000+2200))*2200) /12bitADC
    float Vcc = 3.3;
    float R1 = 37000.0;
    float R2 = 2200.0;
    // Convert ADC value to voltage across R2
    float Vout = (val / 4095.0) * Vcc;

    // Calculate the total voltage across R1 and R2
    float Vin = Vout * (R1 + R2) / R2;

    return Vin;
}
\end{lstlisting}
\newpage
\begin{lstlisting}[language=C, caption=\textbf{float adc\_cur(uint16\_t val)},label={adcC}, mathescape=true, breaklines=true]
/**
  * @brief Converts a raw ADC value to the corresponding current based on shunt resistor and amplification factor
  * @param val    = Raw 12-bit ADC value (0-4095)
  * @retval float = Calculated current in amperes
  */
float adc_cur(uint16_t val){
    float Vcc = 3.3;
    float amplification_factor = 20.0;
    float R_shunt = 0.004;
    float offset_voltage = Vcc / 2.0;

    // Convert ADC value to the amplified voltage
    float Vadc = (val / 4095.0) * Vcc;

    // Adjust for the offset voltage
    float Vadc_adjusted = Vadc - offset_voltage;

    // Determine the actual voltage drop across the shunt
    float Vshunt = Vadc_adjusted / amplification_factor;

    // Calculate the current through the shunt
    float current = Vshunt / R_shunt;
    return current;
}
\end{lstlisting}

\begin{lstlisting}[language=C, caption=\textbf{float adc\_temp(uint16\_t val)},label={adcT}, mathescape=true, breaklines=true]
/**
  * @brief Converts a raw ADC value to the corresponding temperature in Celsius using an NTC thermistor
  * @param val    = Raw 12-bit ADC value (0-4095)
  * @retval float = Calculated temperature in Celsius
  */
float adc_temp(uint16_t val){
    float Vcc = 3.3;
    float R2 = 10000.0;
    float T0 = 298.15; // 25C in Kelvin
    float R0 = 10000.0; // Resistance at 25C
    float B = 2904.0; // Beta parameter

    // Convert ADC value to voltage
    float Vadc = (val / 4095.0) * Vcc;

    // Calculate the resistance of the NTC thermistor
    float R1 = R2 * (Vcc / Vadc - 1.0);
    // Calculate temperature in Kelvin using B-parameter equation
    float T = 1.0 / ((1.0 / T0) + (1.0 / B) * log(R1 / R0));
    // Convert Kelvin to Celsius
    float T_Celsius = T - 273.15;
    return T_Celsius;
}
\end{lstlisting}

\begin{lstlisting}[language=C, caption=\textbf{float rpm\_tokmh(float rpm)},label={kmh}, mathescape=true, breaklines=true]
/**
  * @brief Converts motor RPM to speed in kilometers per hour (km/h) based on wheel circumference
  * @param rpm    = Motor RPM (revolutions per minute)
  * @retval float = Calculated speed in kilometers per hour (km/h)
  */
float rpm_tokmh(float rpm){
	//36inch wheel
	//91,44 cm wheel
	//U = 2*pi*r
	//U = 287,267cm
	//U = 2,87267m
	float circumference = 2.87267;
    // distance traveled per minute in meters
    float distance_per_minute = rpm * circumference;
    // Convert distance to kilometers per hour
    float speed_kmh = distance_per_minute * 60 / 1000;
    return speed_kmh;
}
\end{lstlisting}

\section{stm32f4xx\_it.c/h}
\begin{lstlisting}[language=C, caption=\textbf{void TIM2\_IRQHandler(void)},label={tim2}, mathescape=true, breaklines=true]
/**
  * @brief This function handles TIM2 global interrupt.
  */
void TIM2_IRQHandler(void)
{
	int x = hallCC*10;
	float rev = x/24;
	rpm = rev*60;
	hallCC = 0;
	ADC_VAL[3] = rpm_tokmh(rpm);
	//HAL_GPIO_TogglePin(PB1_LED_RED_GPIO_Port,PB1_LED_RED_Pin);
	if(timcc >= 10){
		timcc = 0;
	}else{
		timcc++;
	}
	 // Increment counter only if in SWFAULT state
	if (STATE == SWFAULT) {
		swfault_time_counter++;
	} else {
		// Reset the counter if leaving SWFAULT state
        swfault_time_counter = 0;
	}
  HAL_TIM_IRQHandler(&htim2);
}
\end{lstlisting}
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

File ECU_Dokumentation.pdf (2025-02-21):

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

Vorwort Um das Lesen zu vereinfachen, wurde die Dokumentation in vier Teile unterteilt. Diese vier Abschnitte beschäftigen sich jeweils vollständig mit einem Aspekt des Projekts und stehen für sich:
Teil 1: Einleitung und Beschreibung des vollständigen Systems.
Teil 2: Dokumentation des fertigen Schaltplans, Layouts, der Software und Mechanik im Detail.
Teil 3: Der Entwicklungsprozess mit Designänderungen und deren Hintergründen. Teil 4: Anhänge, einschlieÿlich des vollständigen Schaltplans und Quellausschnitte.

Die vollständige Dokumentation sowie der vollständige und durchgehend verfügbare Software-Quellcode, Schaltpläne und weitere Dateien stehen ebenfalls in digitaler Form auf GitHub unter https://github.com/leonreeh/E-Bike-ECU zur Verfügung.

Lizenz Dieses Projekt und die hier beiliegende dokumentation fallen unter die MIT-Lizenz (X11-Lizenz) Leon Reeh 2025

2

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

9.1. (Texas Instruments. (2015). Trapezoidal Control of BLDC Motors Using Hall Eect Sensors . C2000 Systems and Applications Team, Bilal Akin,
9.2. (Texas Instruments. (2015). Trapezoidal Control of BLDC Motors Using Hall Eect Sensors . C2000 Systems and Applications Team, Bilal Akin,

6

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

# 1. Einleitung
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

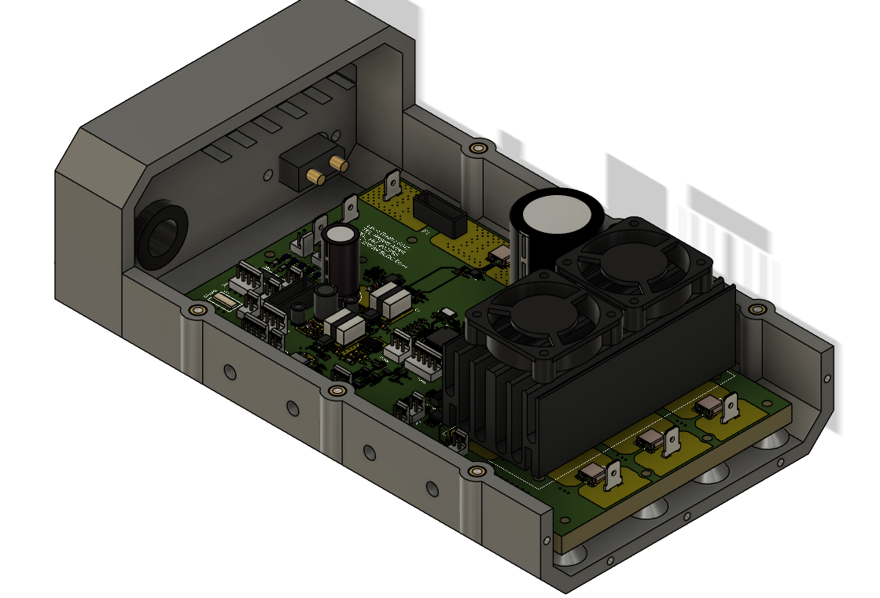
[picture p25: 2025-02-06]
LaTex/Bilder/PCBrender.PNG

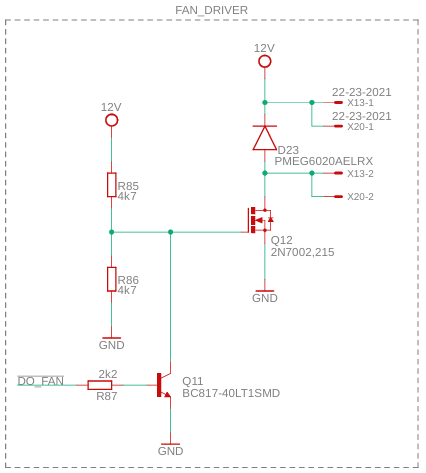
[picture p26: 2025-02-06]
LaTex/Bilder/Fan.PNG

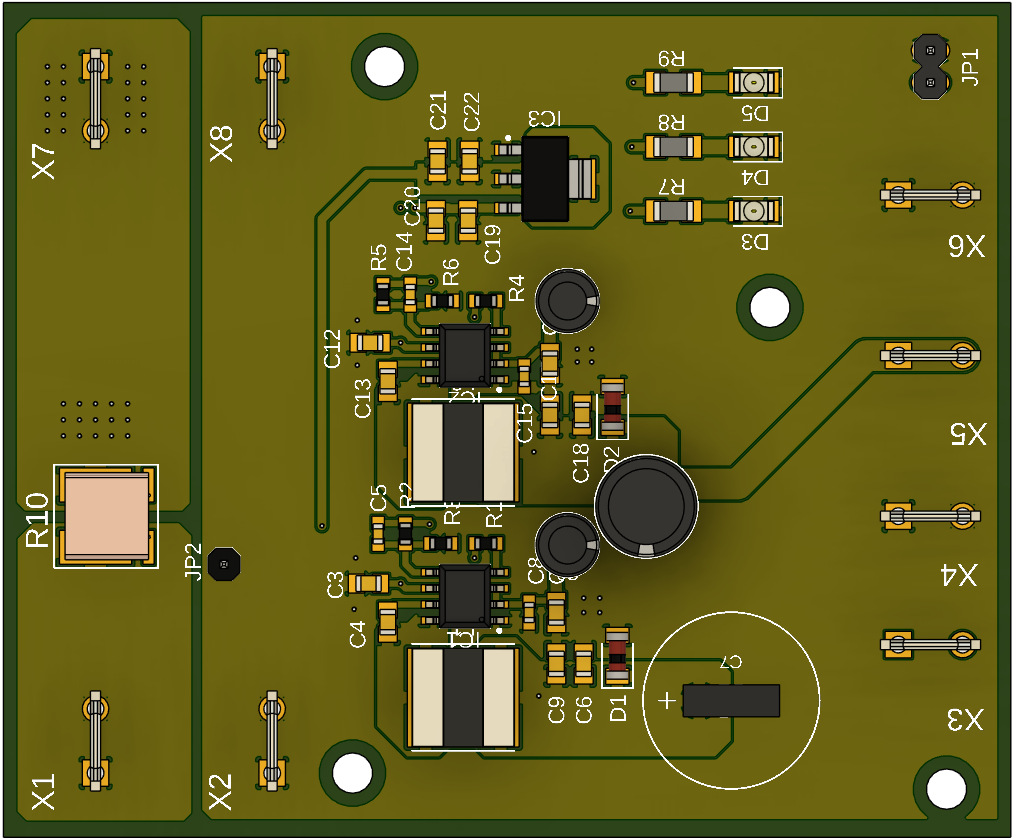
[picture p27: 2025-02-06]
LaTex/Bilder/PSU_V2TOP.PNG

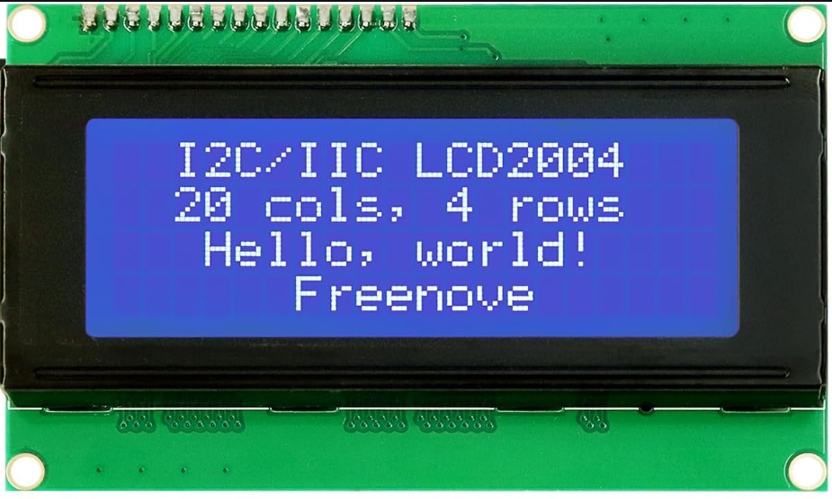
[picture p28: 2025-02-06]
LaTex/Bilder/Displaypic.PNG

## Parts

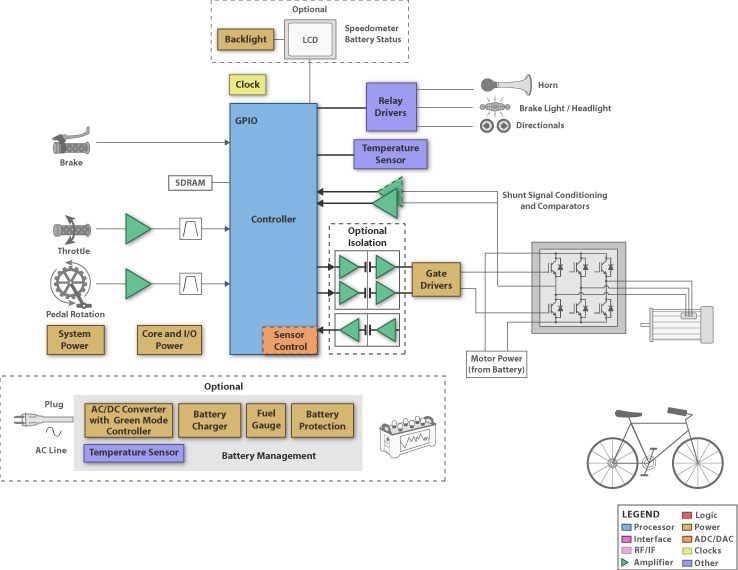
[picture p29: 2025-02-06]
LaTex/Bilder/electromechanical-components-motors-and-controllers-ti-ebike.webp

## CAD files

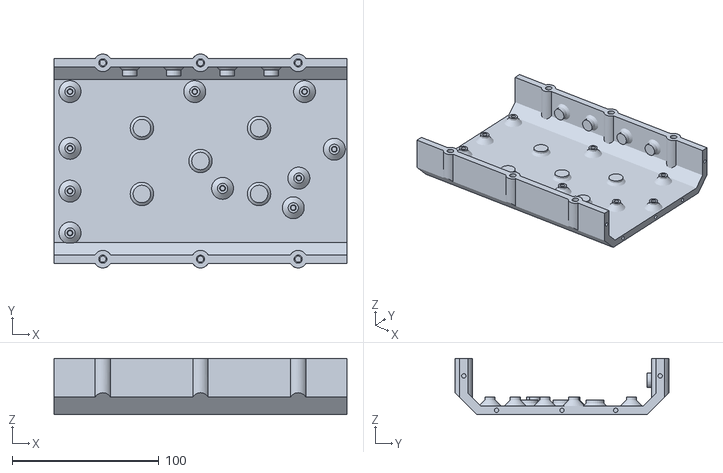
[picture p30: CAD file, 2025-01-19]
Gehäuse STL/Platinen_träger.stl
200.0 x 146.0 x 38.5

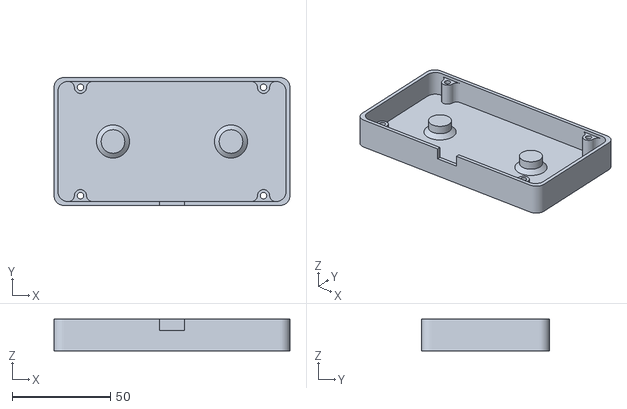
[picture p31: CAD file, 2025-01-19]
LCD Case/LCD_CASE_Bottom.stl
120.0 x 65.0 x 16.2

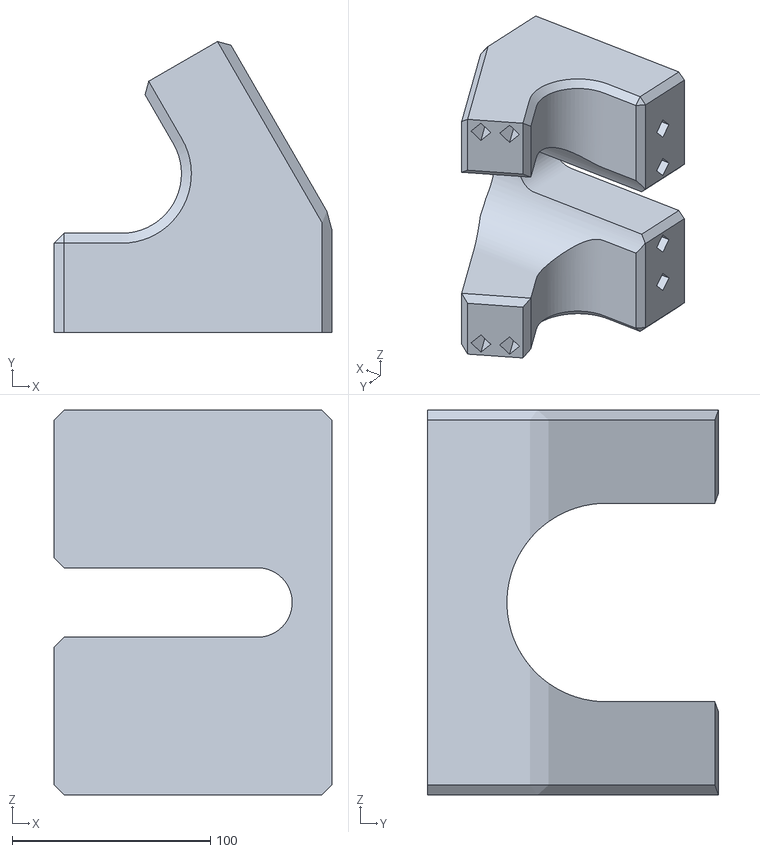
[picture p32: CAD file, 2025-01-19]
MotorTeststand/Foot R.stl
140.0 x 146.6 x 194.0

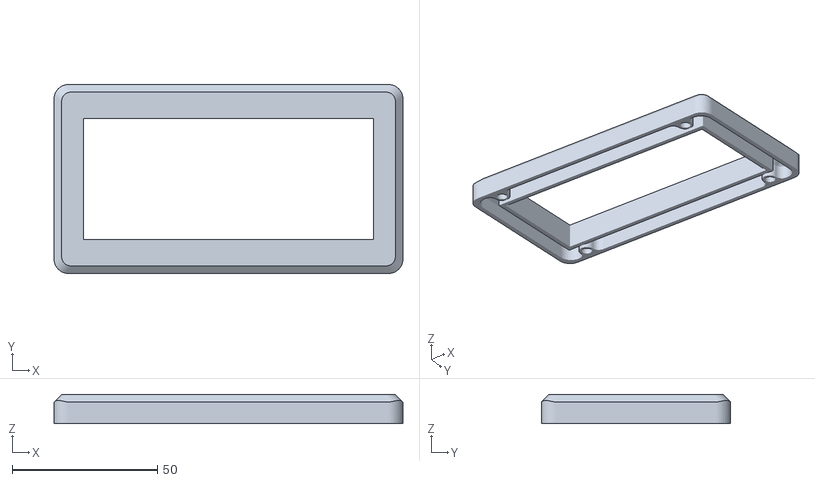
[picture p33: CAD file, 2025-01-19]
LCD Case/LCD_CASE_TOP.stl
120.0 x 65.0 x 10.0

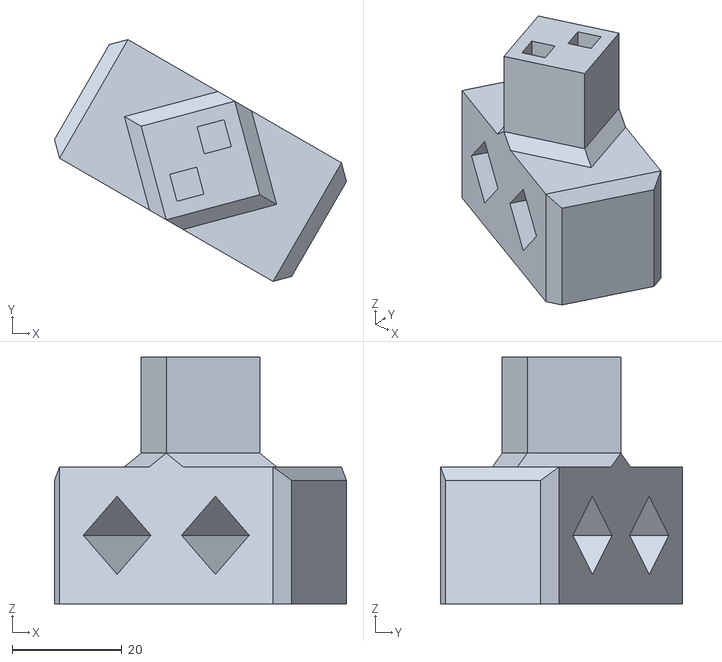
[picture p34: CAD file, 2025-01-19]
MotorTeststand/Support R.stl
53.3 x 44.2 x 45.0

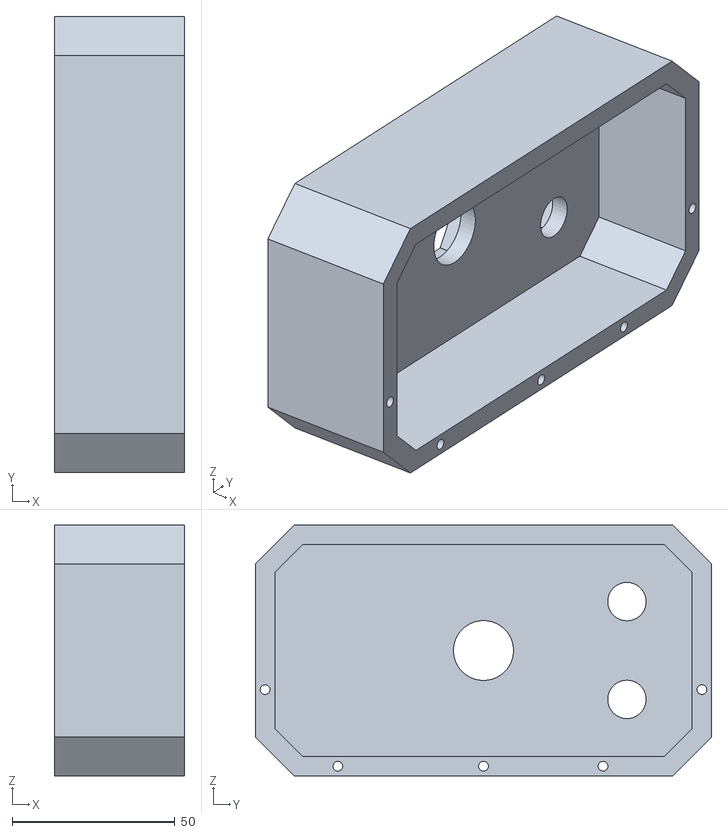
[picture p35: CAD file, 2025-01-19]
Gehäuse STL/Heck.stl
40.0 x 140.0 x 77.0

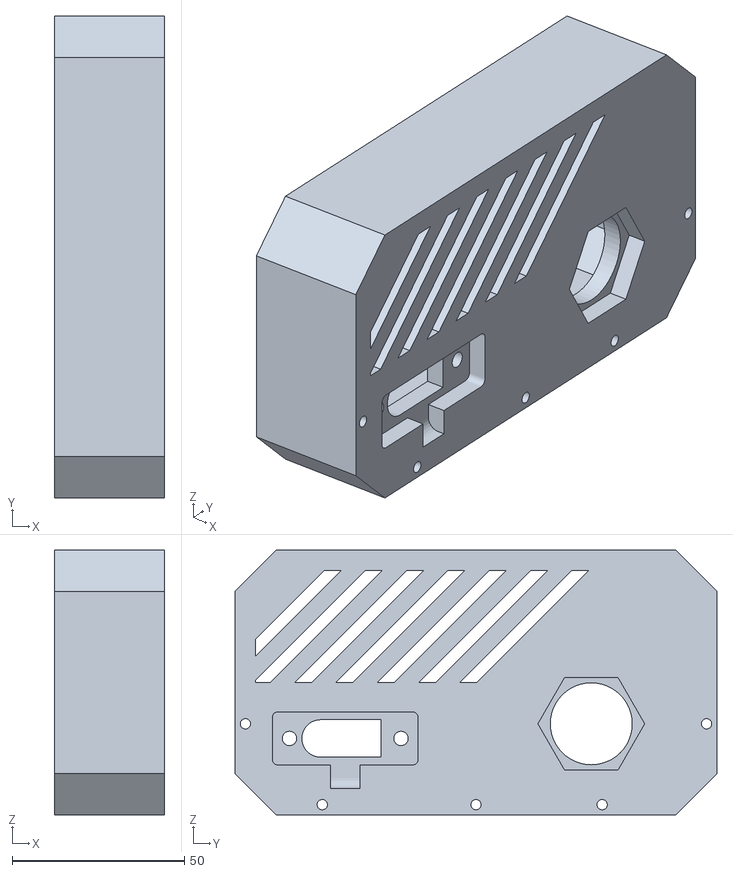
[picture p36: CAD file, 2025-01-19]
Gehäuse STL/Front.stl
32.0 x 140.0 x 77.0

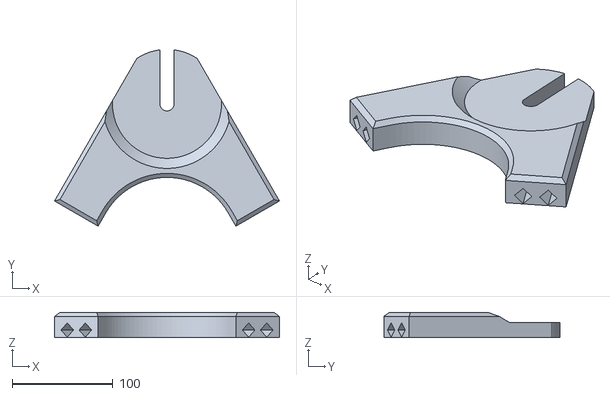
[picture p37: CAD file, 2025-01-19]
MotorTeststand/Flansch L.stl
223.3 x 175.0 x 25.0

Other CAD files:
Gehäuse STL/Deckel.stl
MotorTeststand/Foot L.stl
MotorTeststand/Support L.stl
MotorTeststand/Flansch R.stl

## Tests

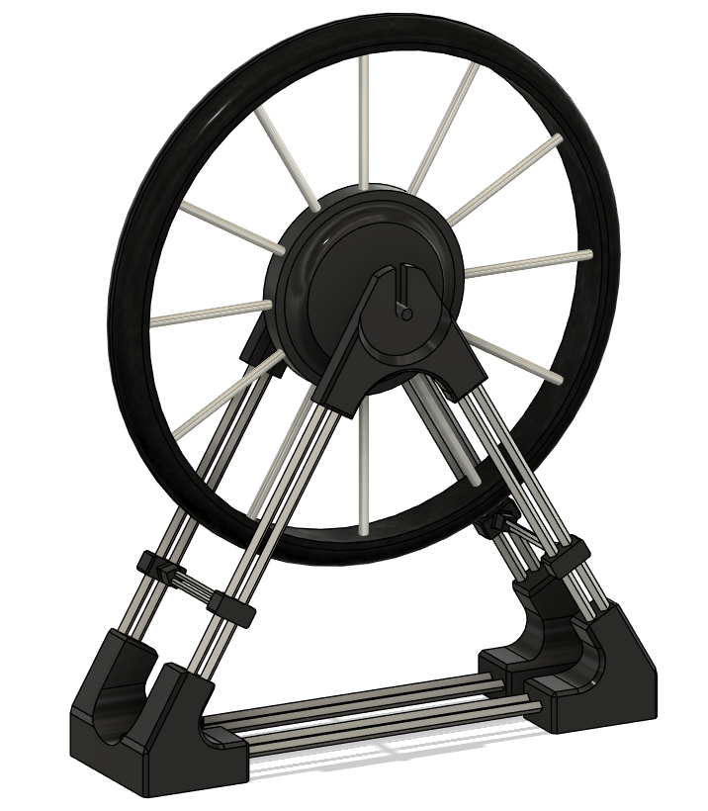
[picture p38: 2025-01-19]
MotorTeststand/MotorTeststand.PNG

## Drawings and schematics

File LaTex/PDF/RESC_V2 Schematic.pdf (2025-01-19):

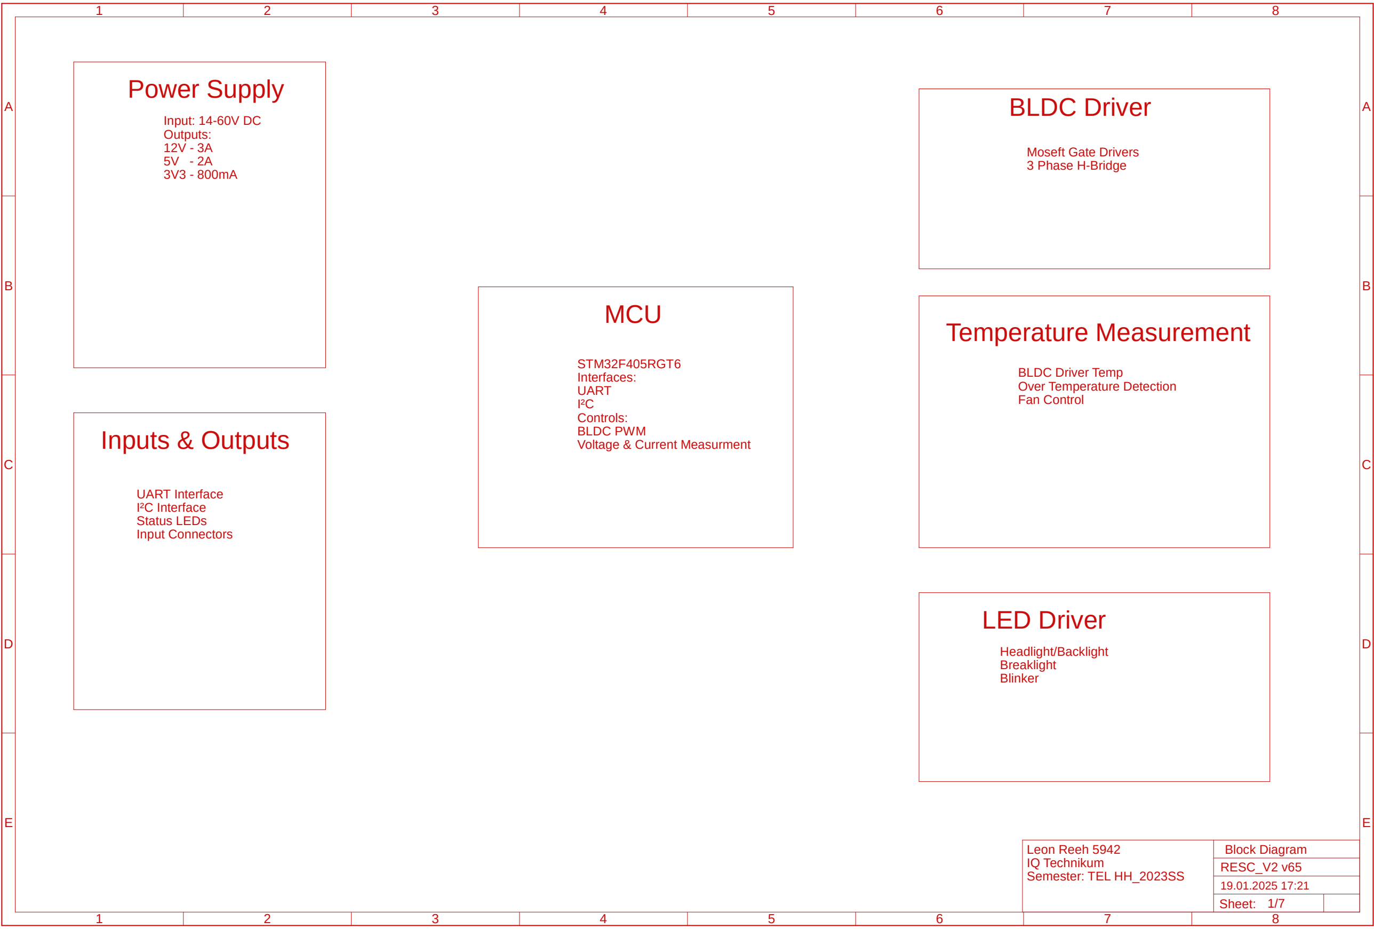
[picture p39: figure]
Power Supply; MCU; BLDC Driver; LED Driver; Inputs & Outputs; Temperature Measurement; Input: 14-60V DC Outputs: 12V - 3A 5V - 2A 3V3 - 800mA; Headlight/Backlight Breaklight Blinker; BLDC Driver Temp Over Temperature Detection Fan Control; UART Interface I²C Interface Status LEDs Input Connectors; STM32F405RGT6 Interfaces: UART I²C Controls: BLDC PWM Voltage & Current Measurment; Moseft Gate Drivers 3 Phase H-Bridge; Leon Reeh 5942 IQ Technikum Semester: TEL HH_2023SS; Block Diagram RESC_V2 v65 19.01.2025 17:21 Sheet: 1/7

A

A

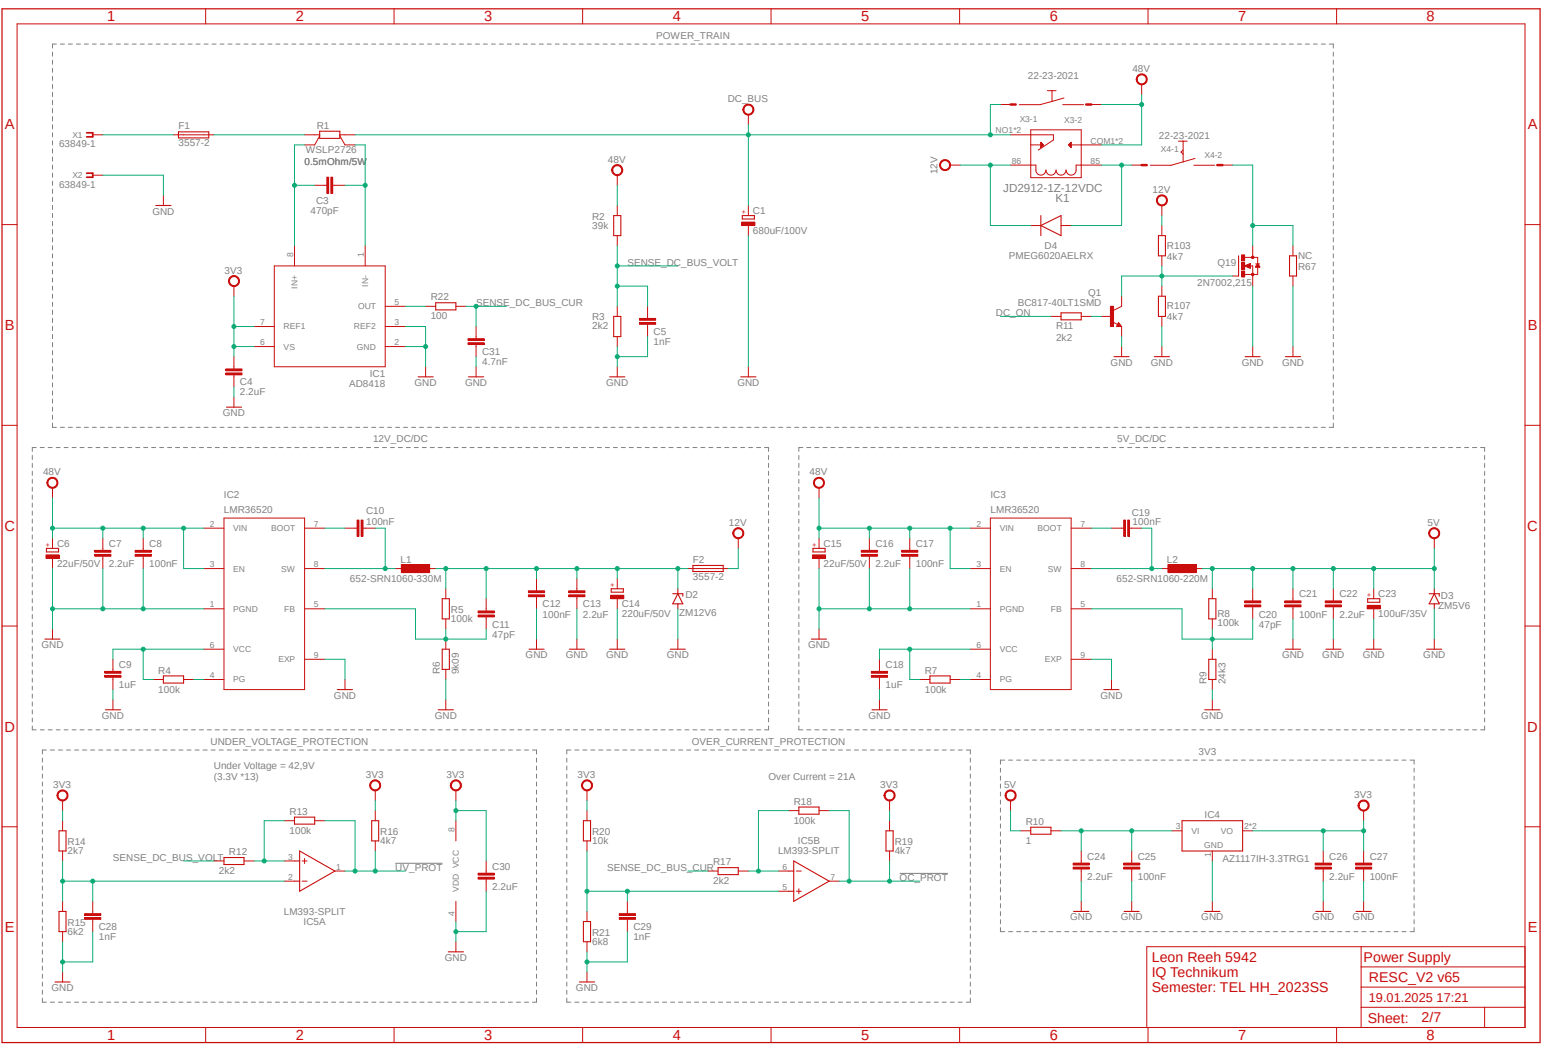
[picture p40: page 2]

A

A

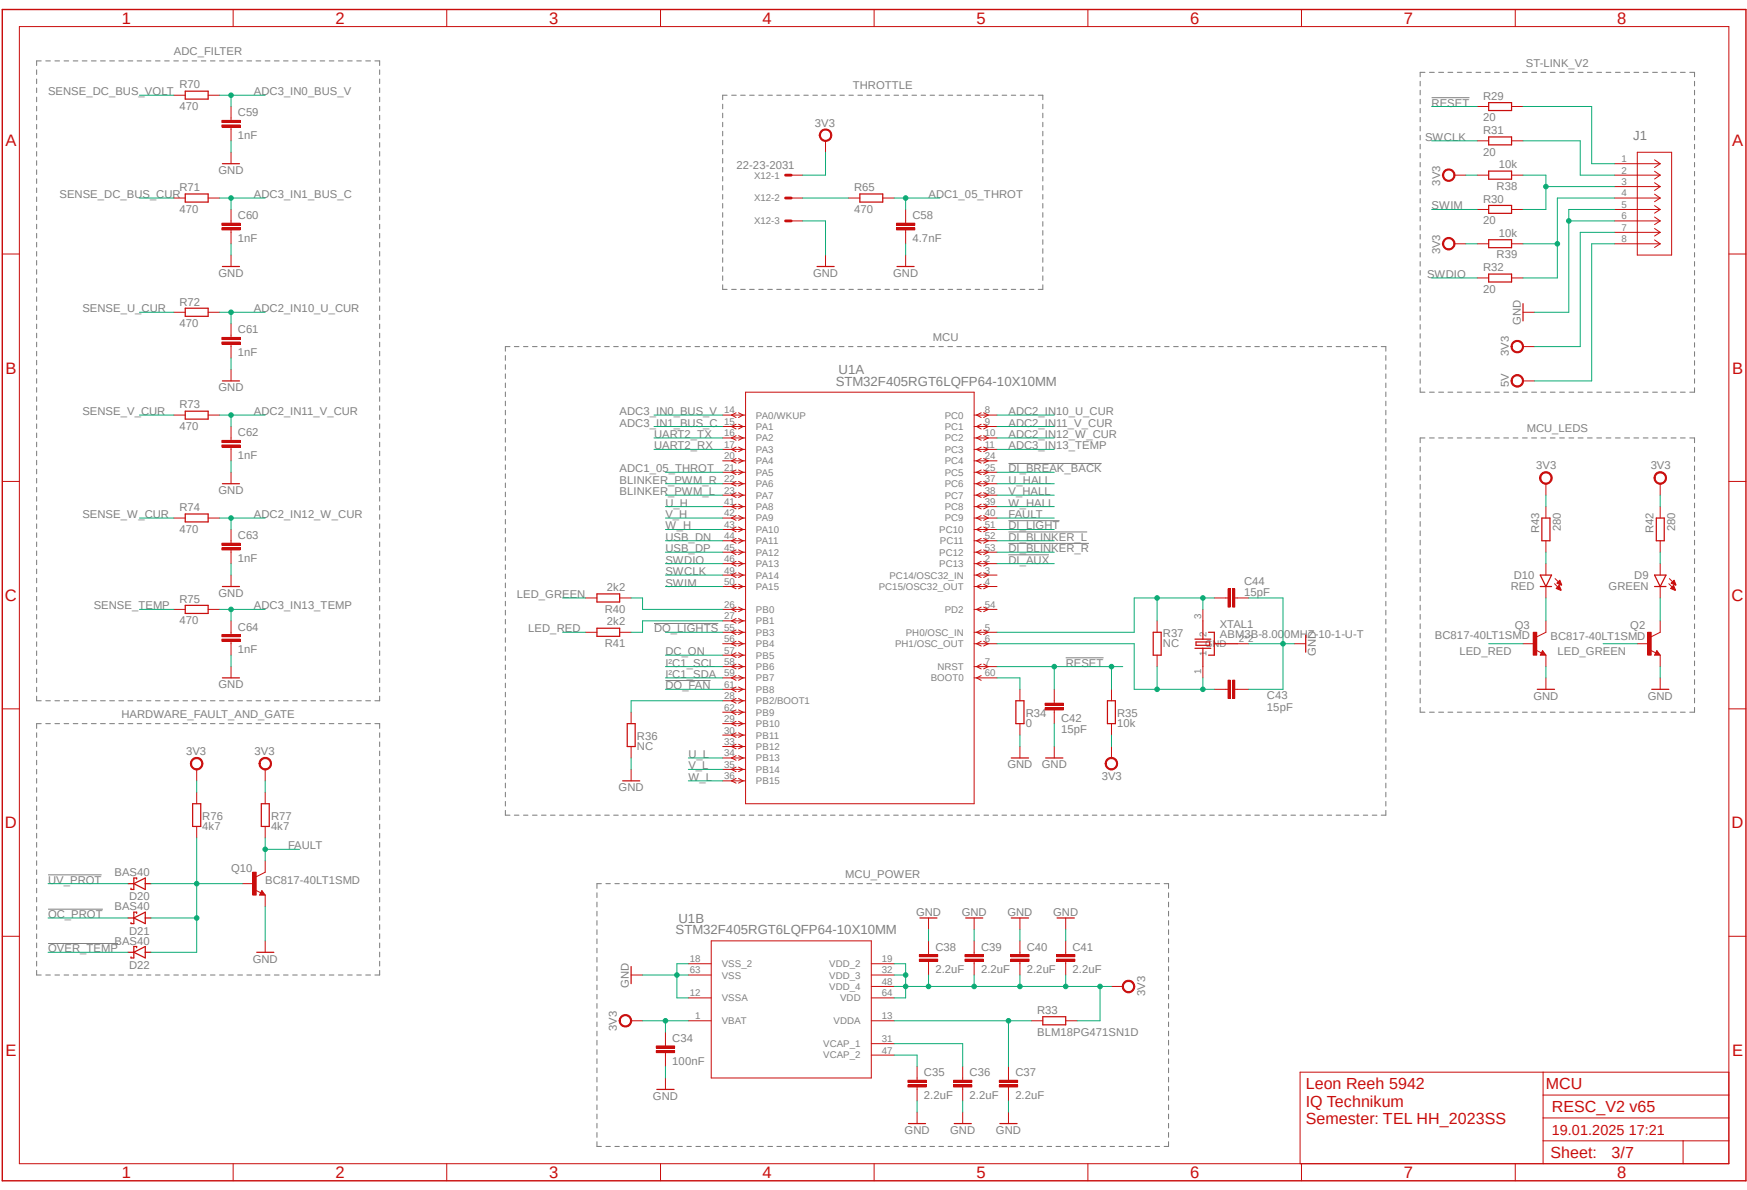
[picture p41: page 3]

A

A

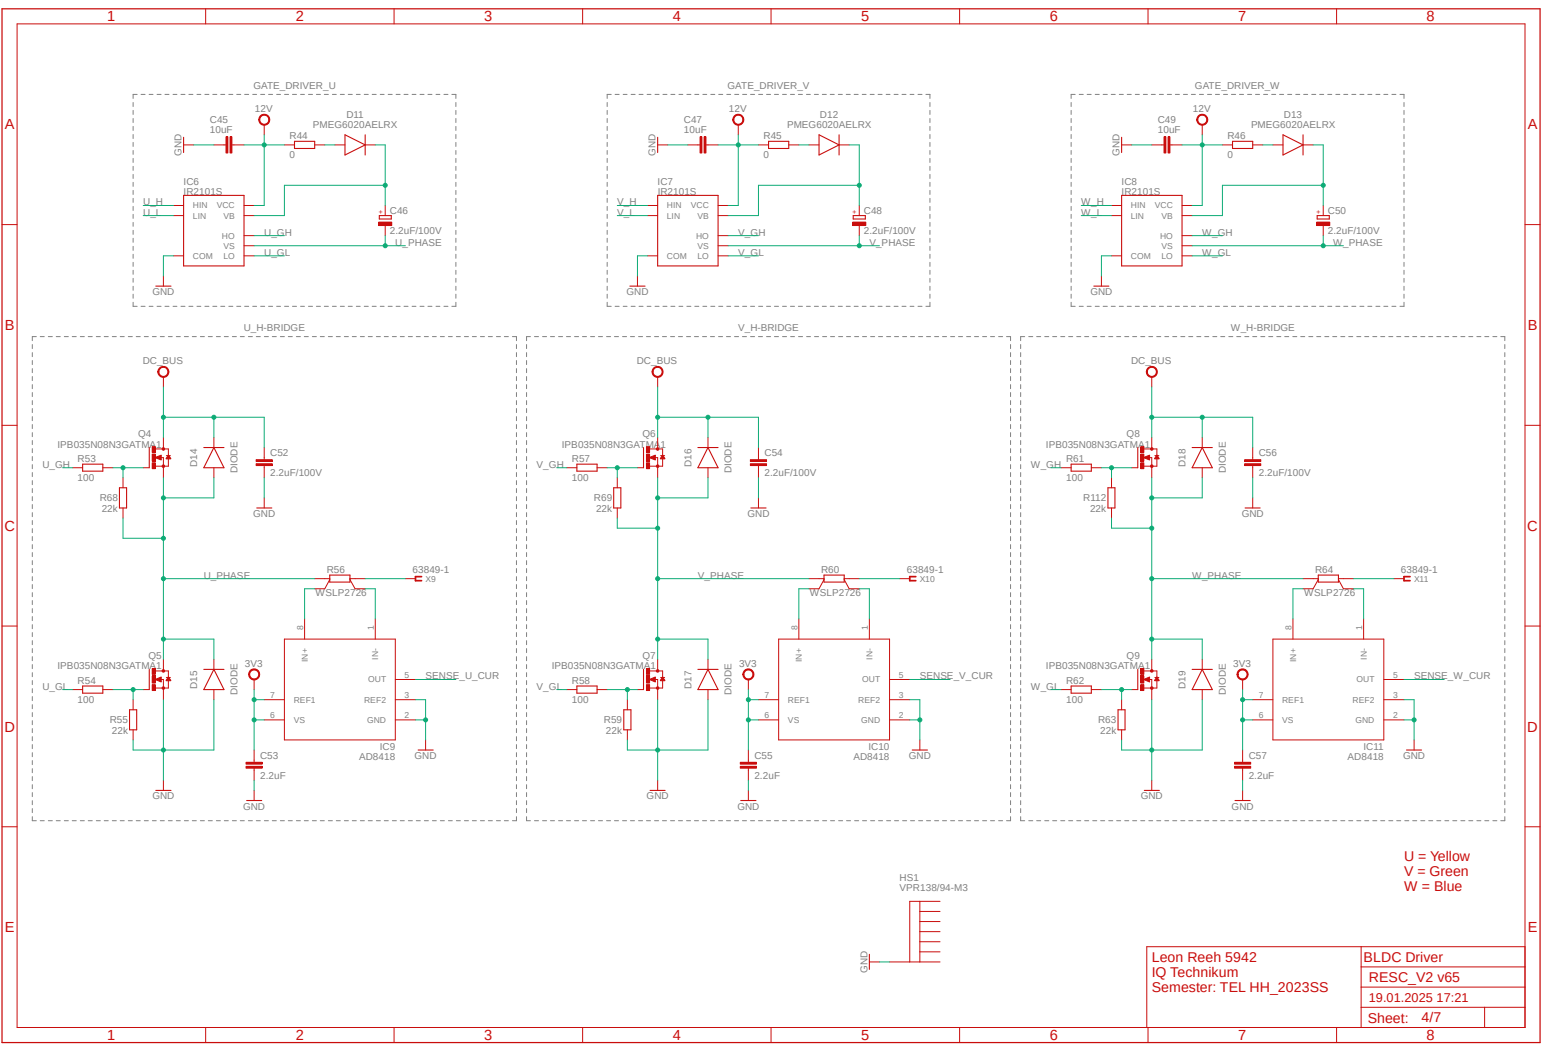
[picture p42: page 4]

A

A

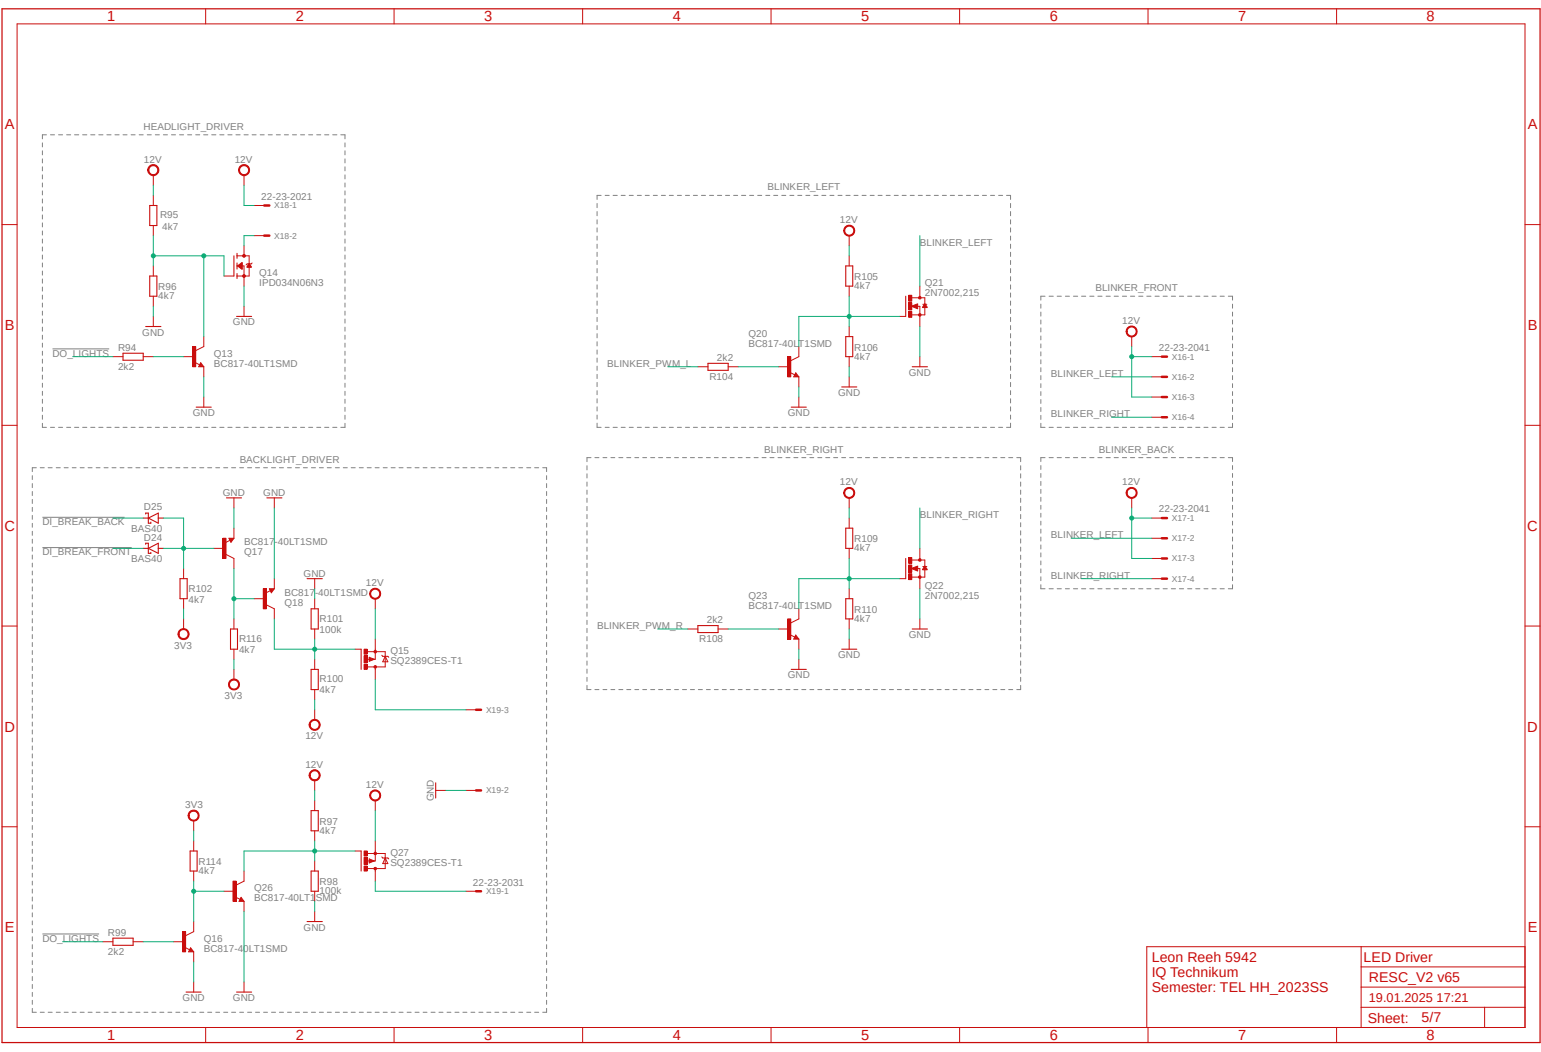
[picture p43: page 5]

A

A

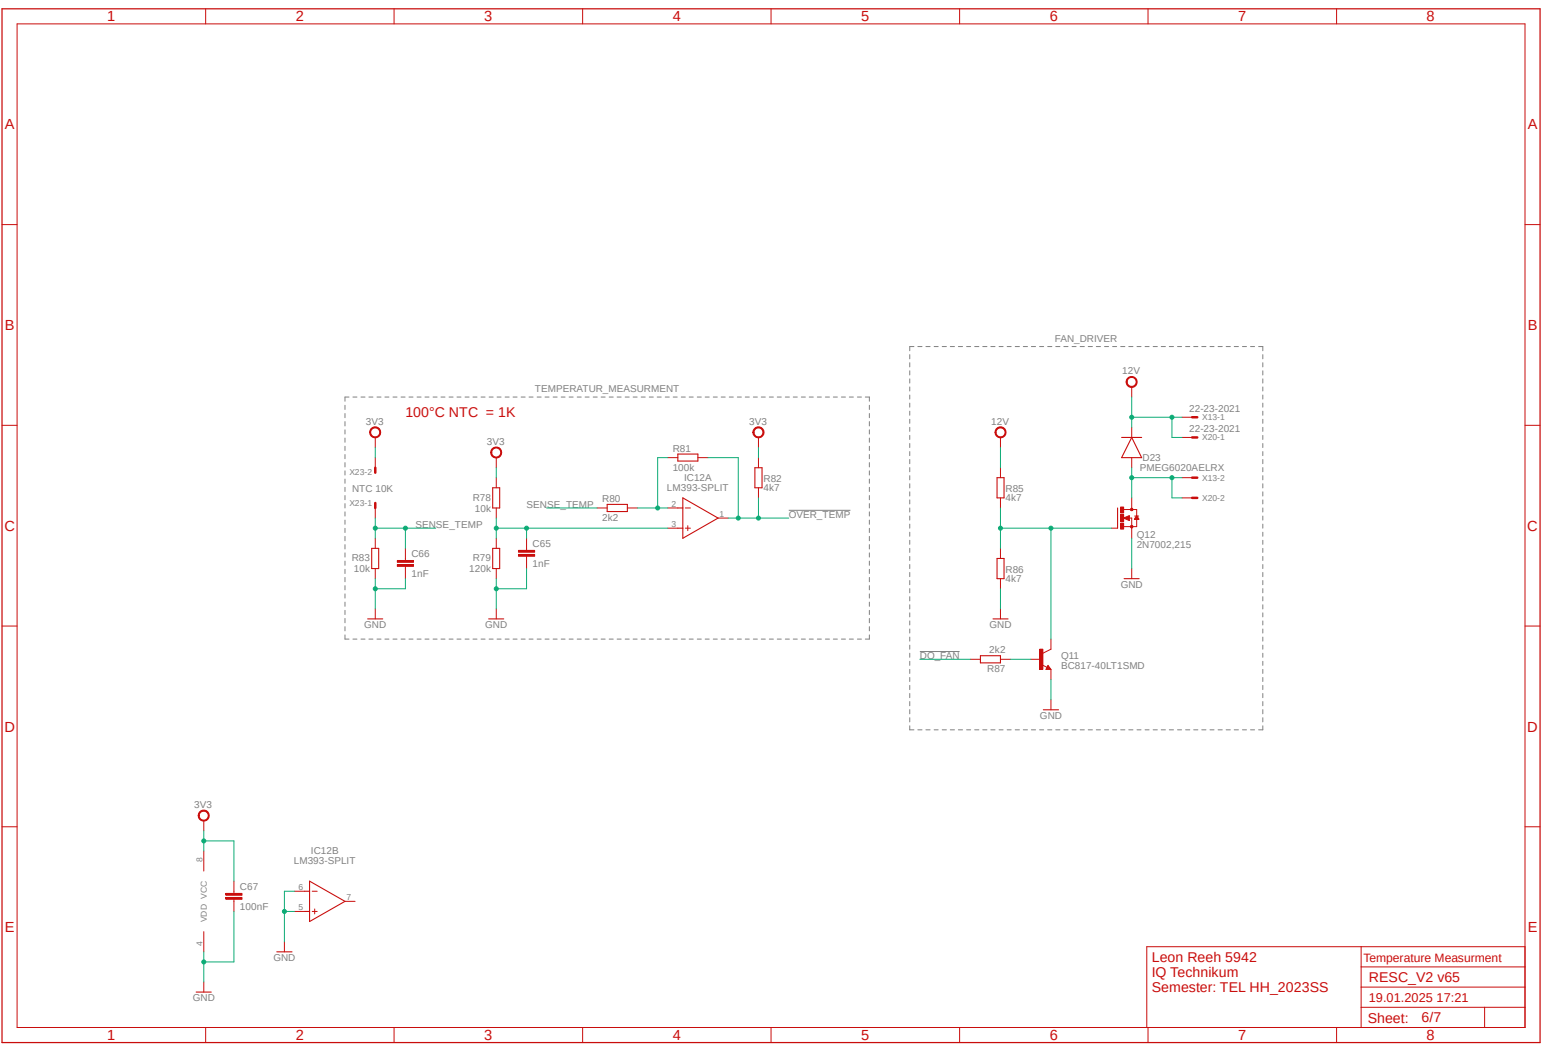
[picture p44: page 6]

A

A

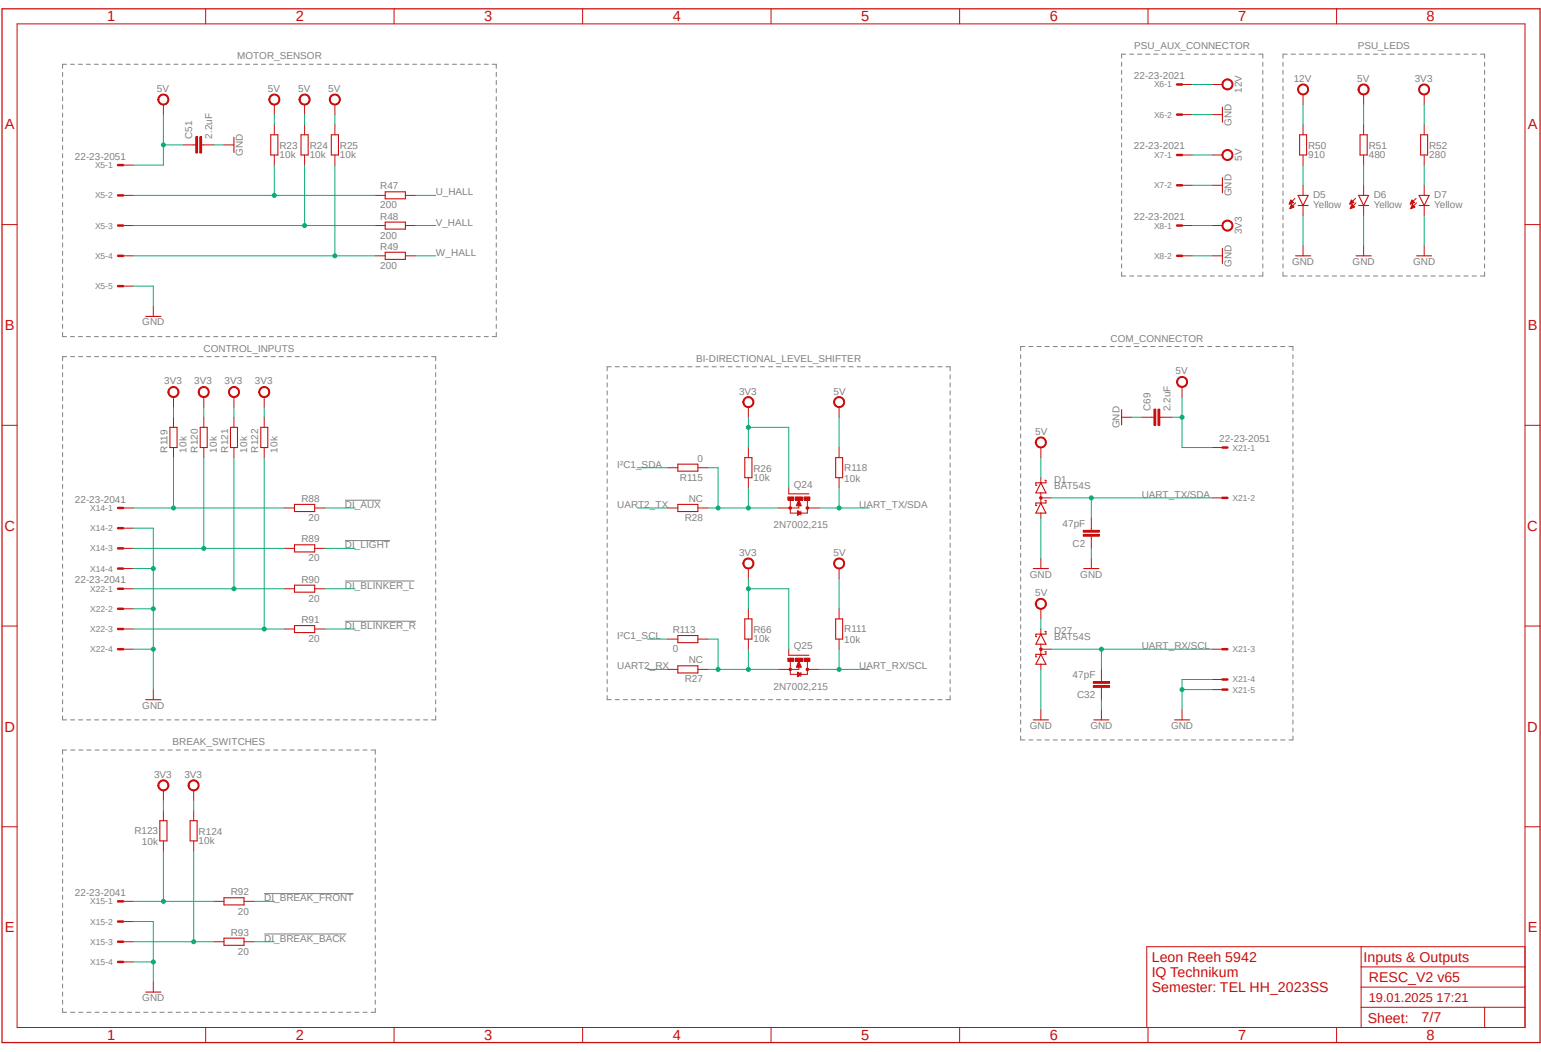
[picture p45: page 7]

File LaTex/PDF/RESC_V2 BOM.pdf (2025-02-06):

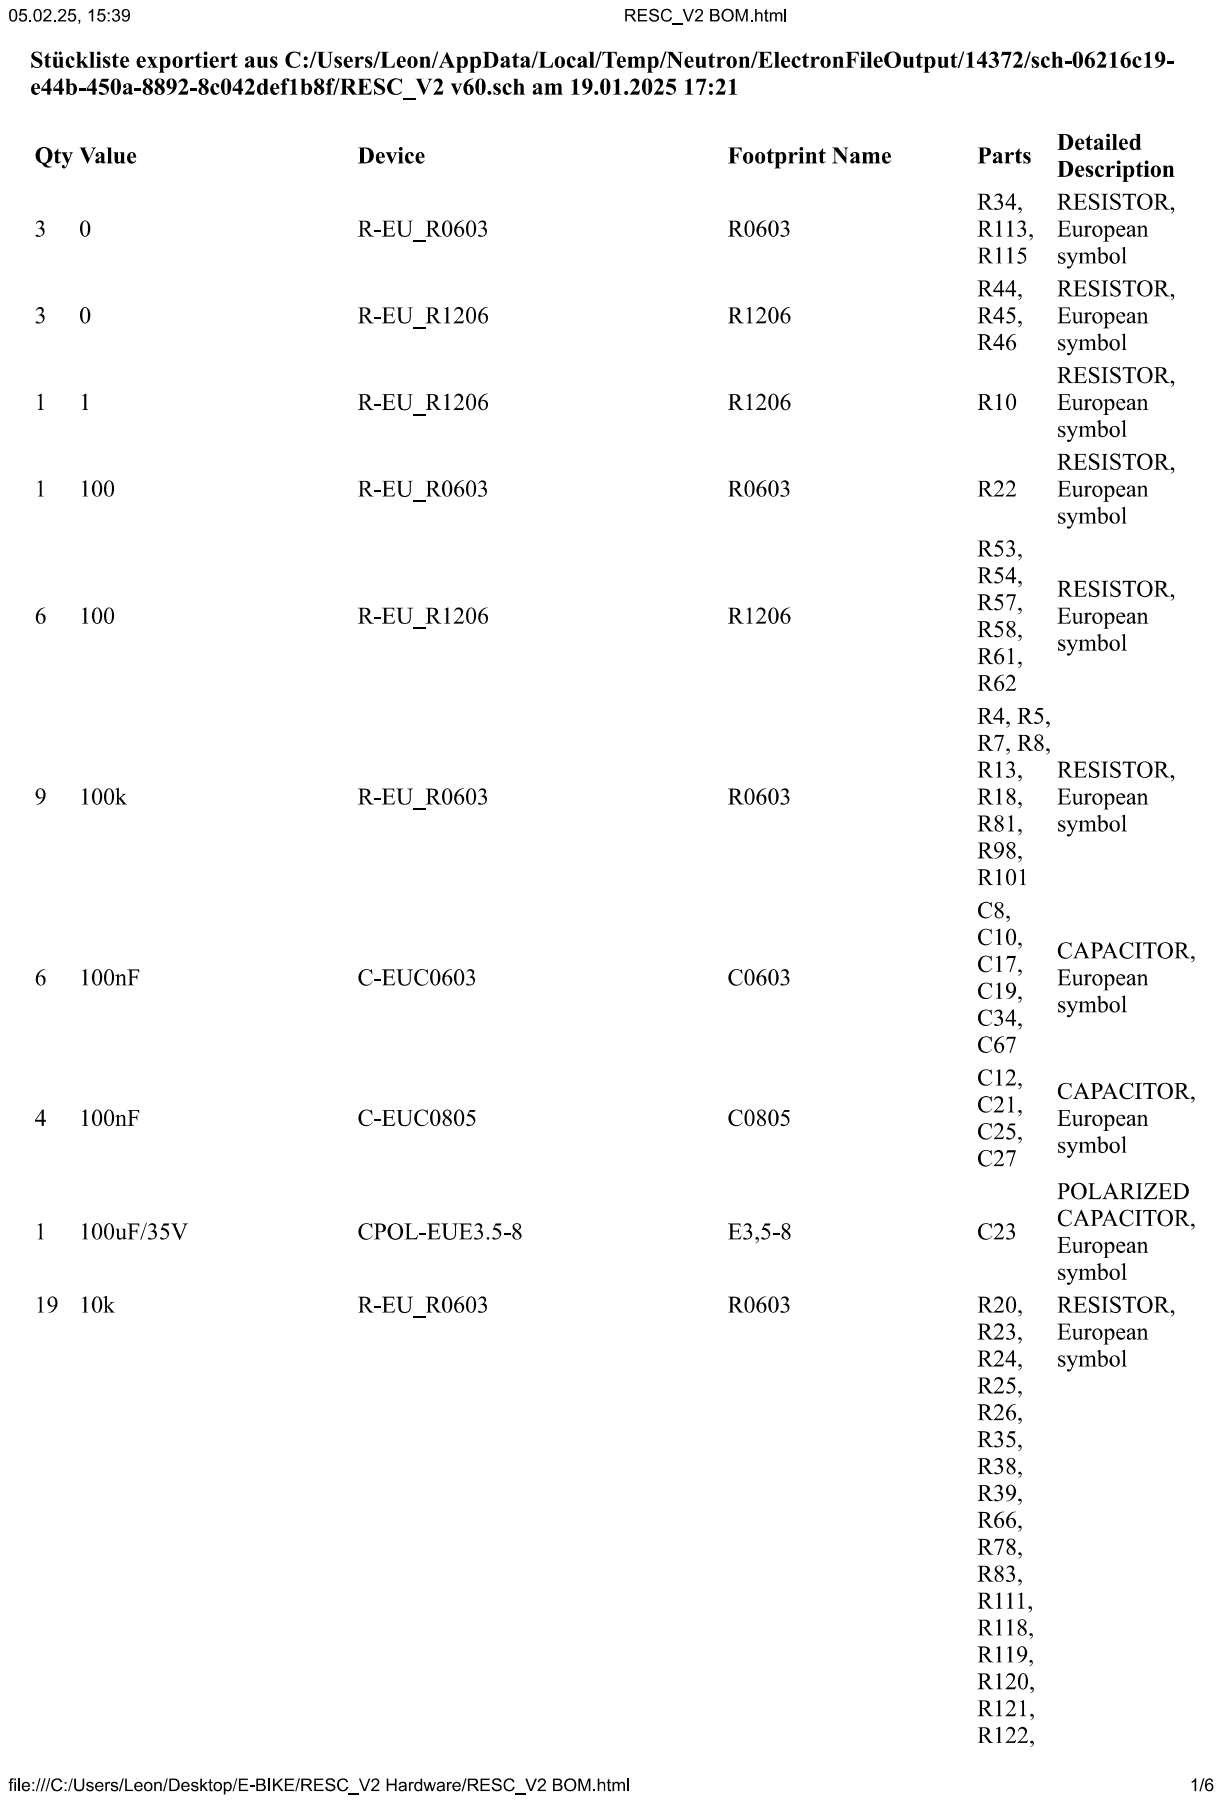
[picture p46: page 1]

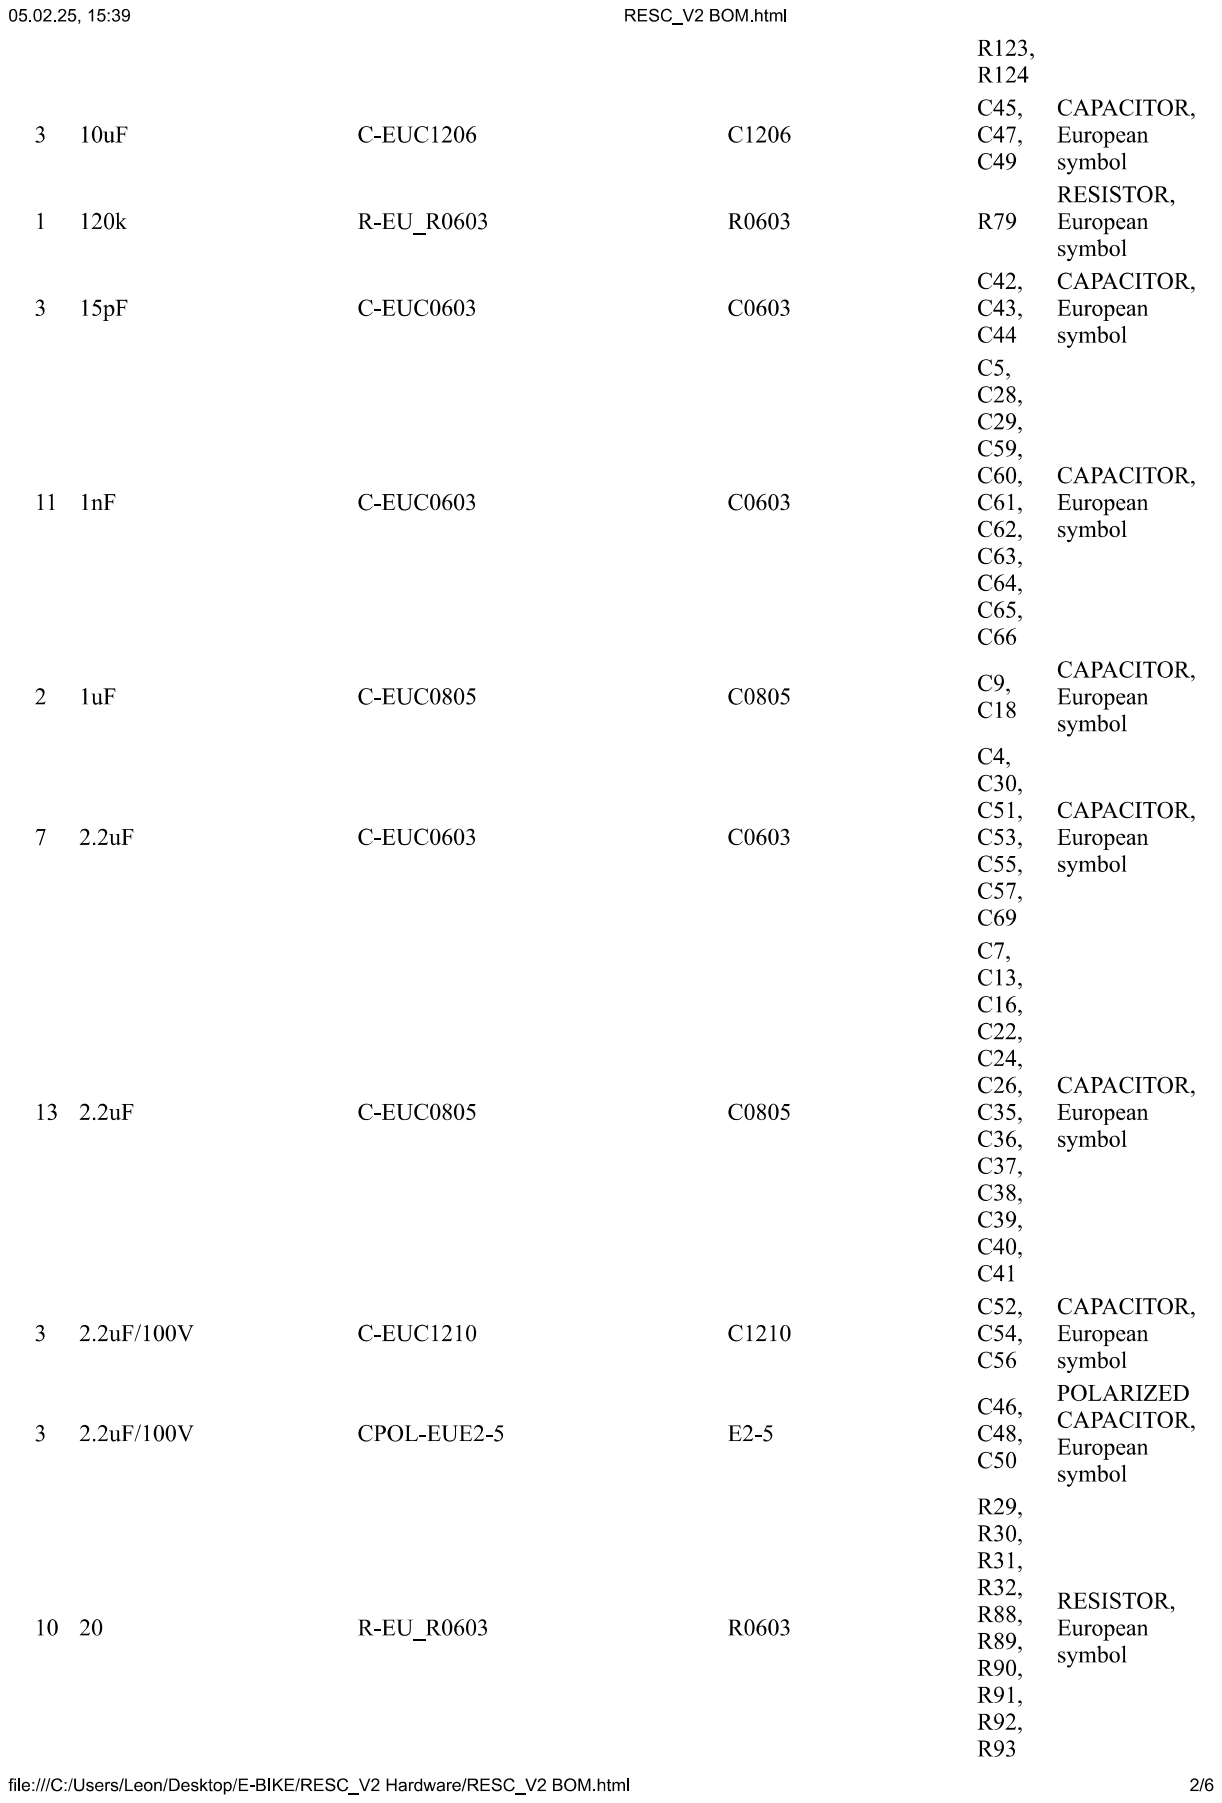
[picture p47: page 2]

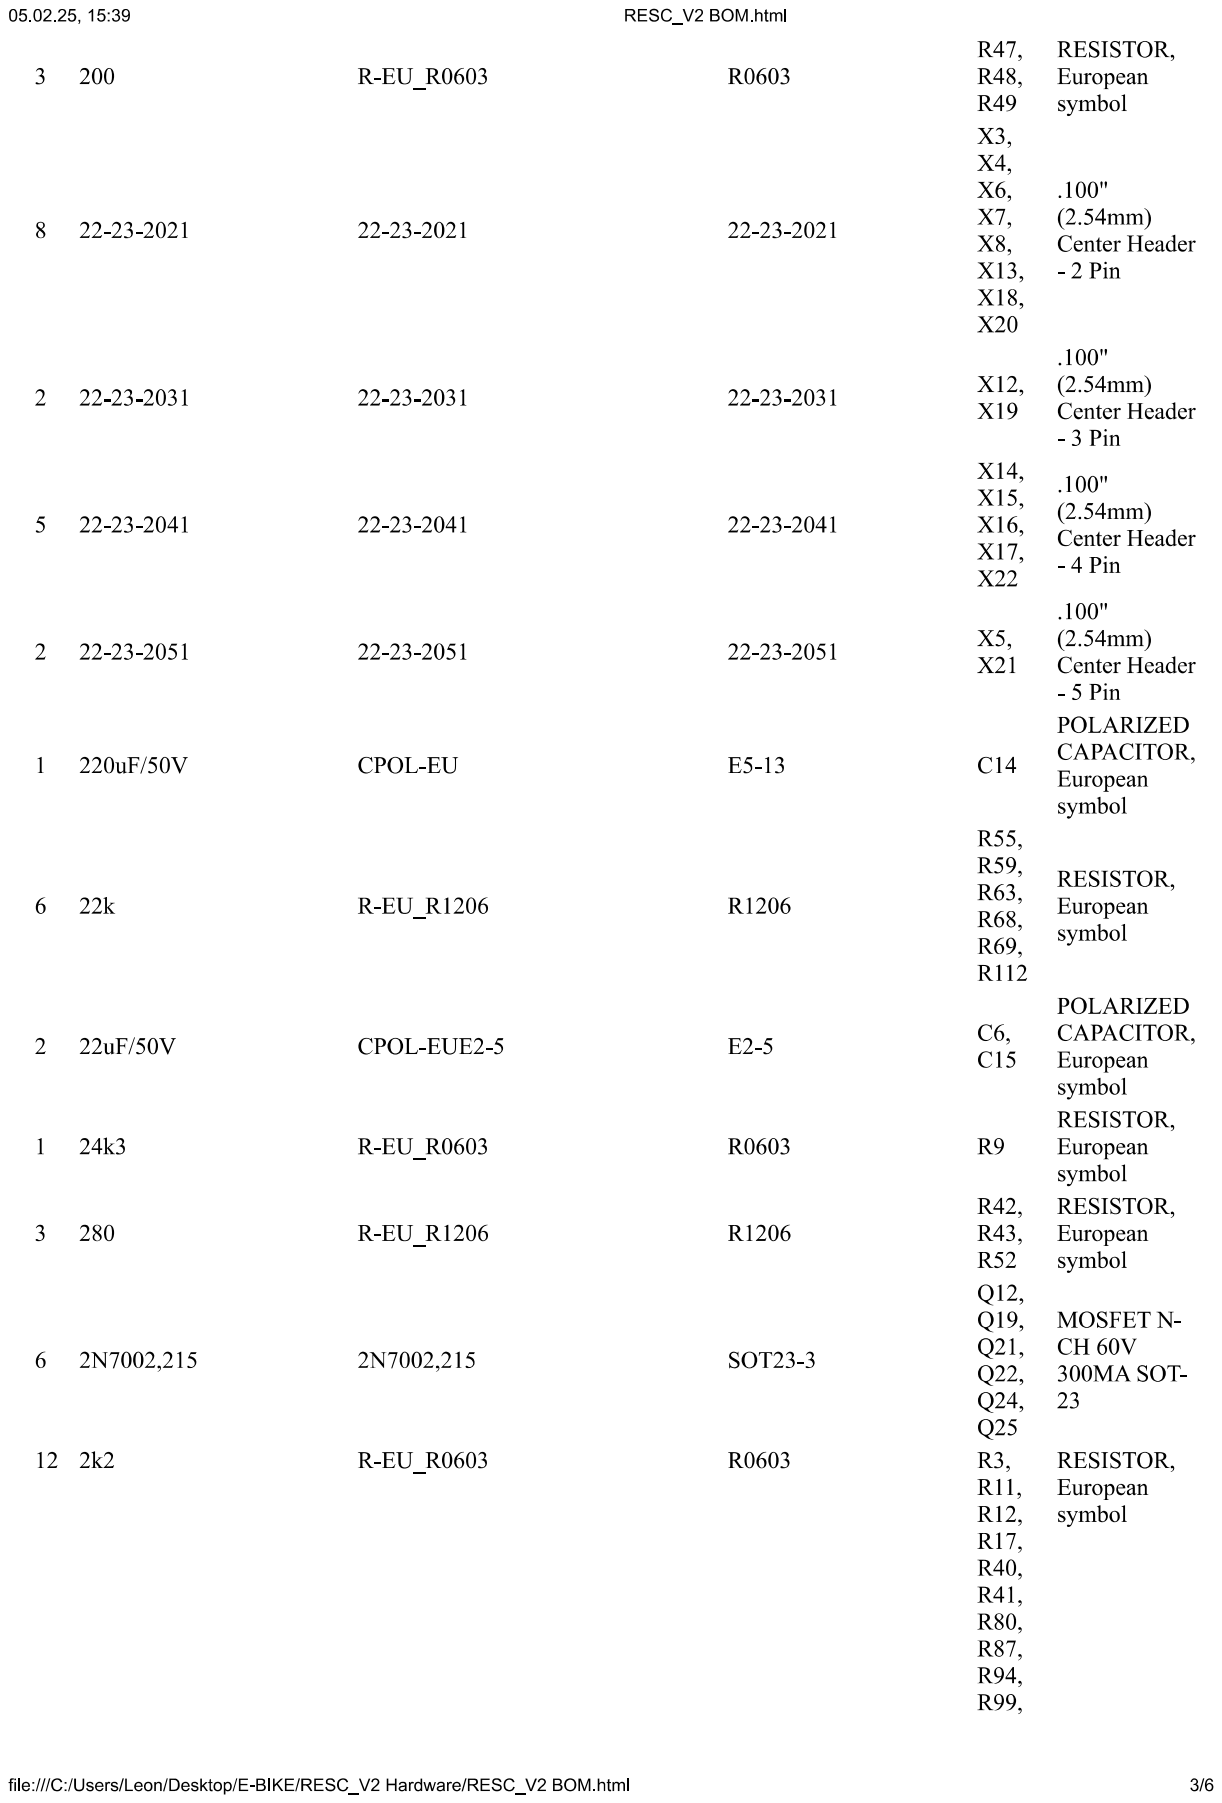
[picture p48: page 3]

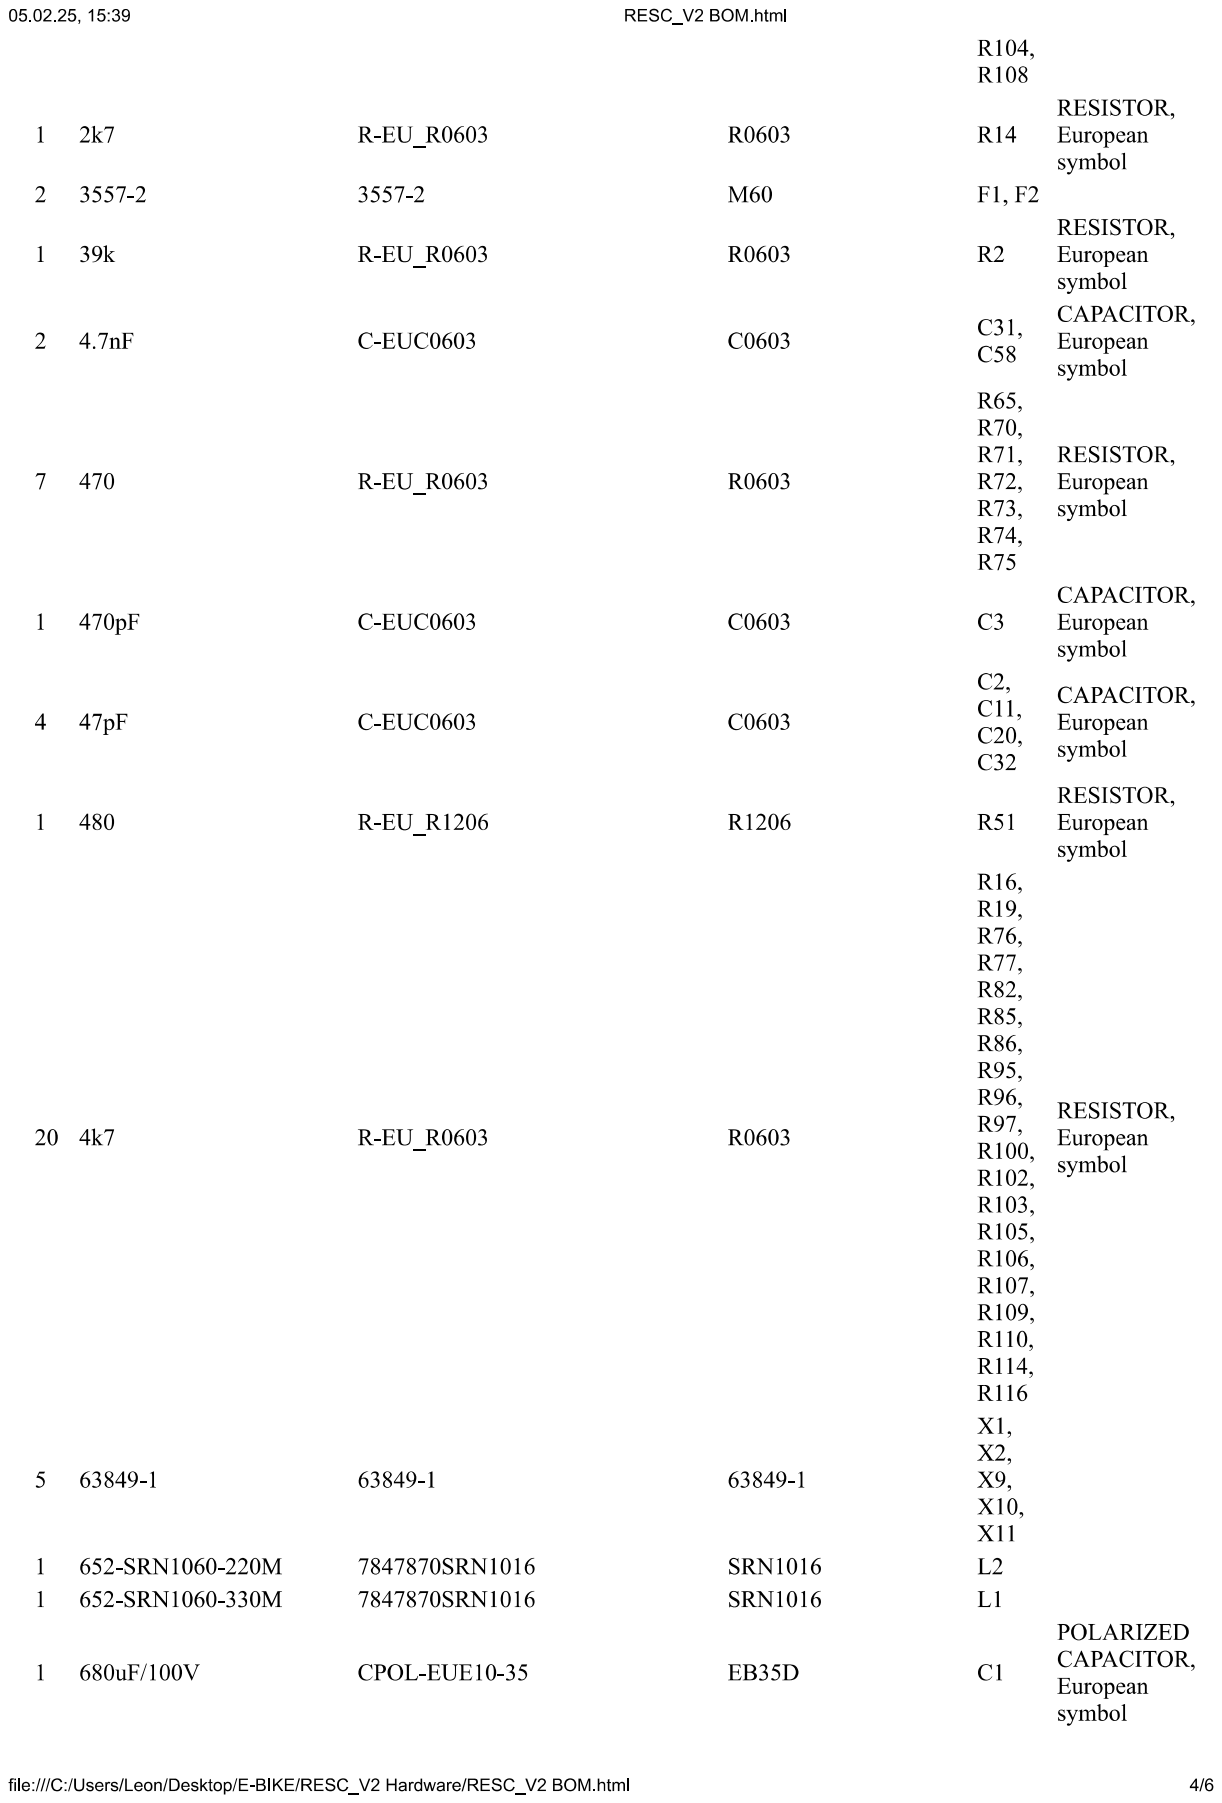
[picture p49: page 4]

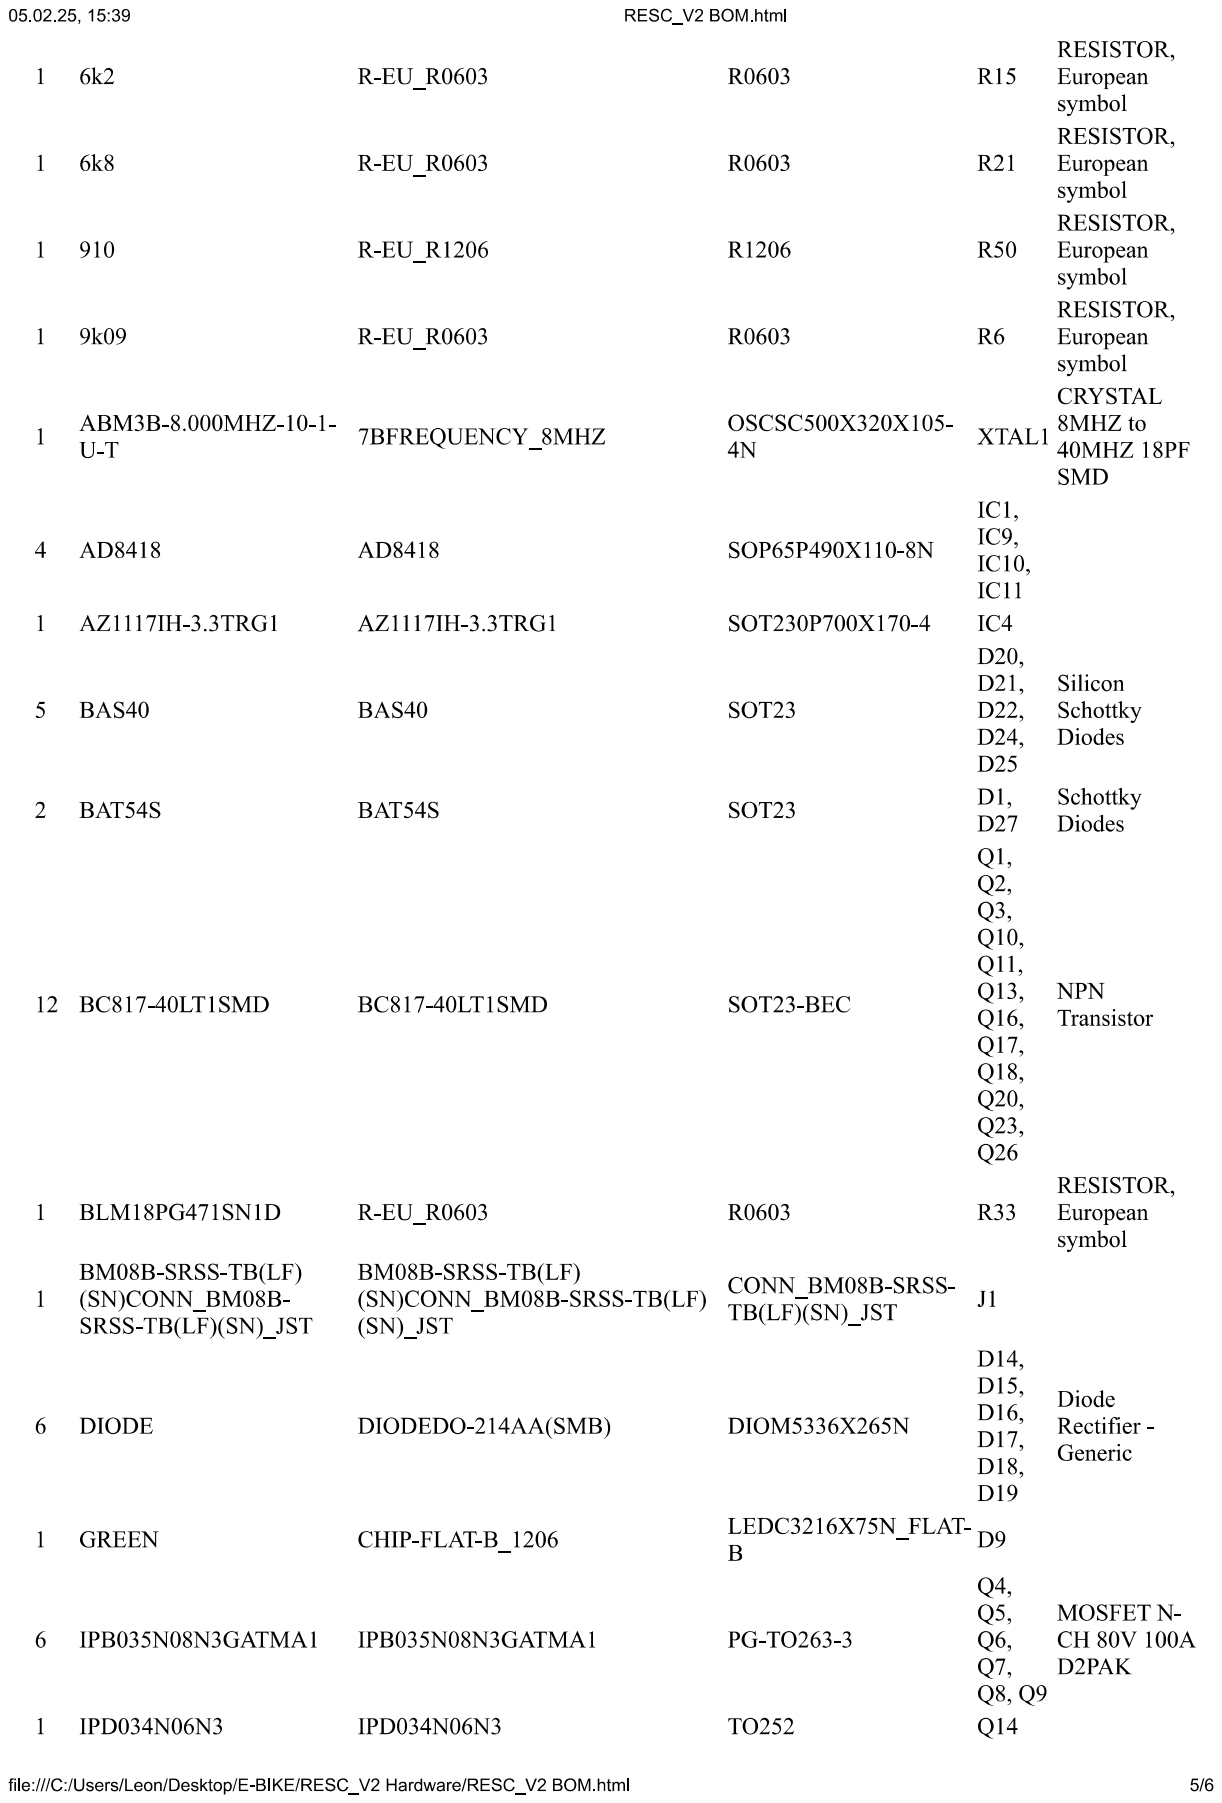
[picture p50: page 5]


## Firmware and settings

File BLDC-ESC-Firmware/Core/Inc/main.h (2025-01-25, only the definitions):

#define PC13_DI_AUX_Pin GPIO_PIN_13
#define PC13_DI_AUX_GPIO_Port GPIOC
#define ADC2_IN10_U_CUR_Pin GPIO_PIN_0
#define ADC2_IN10_U_CUR_GPIO_Port GPIOC
#define ADC2_IN11_V_CUR_Pin GPIO_PIN_1
#define ADC2_IN11_V_CUR_GPIO_Port GPIOC
#define ADC2_IN12_W_CUR_Pin GPIO_PIN_2
#define ADC2_IN12_W_CUR_GPIO_Port GPIOC
#define ADC3_IN13_TEMP_Pin GPIO_PIN_3
#define ADC3_IN13_TEMP_GPIO_Port GPIOC
#define ADC3_IN0_BUS_VOLT_Pin GPIO_PIN_0
#define ADC3_IN0_BUS_VOLT_GPIO_Port GPIOA
#define ADC3_IN1_BUS_CUR_Pin GPIO_PIN_1
#define ADC3_IN1_BUS_CUR_GPIO_Port GPIOA
#define ADC1_IN5_Throttle_Pin GPIO_PIN_5
#define ADC1_IN5_Throttle_GPIO_Port GPIOA
#define TIM3_CH1_Blinker_R_Pin GPIO_PIN_6
#define TIM3_CH1_Blinker_R_GPIO_Port GPIOA
#define TIM3_CH2_Blinker_L_Pin GPIO_PIN_7
#define TIM3_CH2_Blinker_L_GPIO_Port GPIOA
#define EXTI5_Break_Pin GPIO_PIN_5
#define EXTI5_Break_GPIO_Port GPIOC
#define EXTI5_Break_EXTI_IRQn EXTI9_5_IRQn
#define PB1_LED_RED_Pin GPIO_PIN_0
#define PB1_LED_RED_GPIO_Port GPIOB
#define PB0_LED_GREEN_Pin GPIO_PIN_1
#define PB0_LED_GREEN_GPIO_Port GPIOB
#define PB13_U_Pin GPIO_PIN_13
#define PB13_U_GPIO_Port GPIOB
#define PB14_V_Pin GPIO_PIN_14
#define PB14_V_GPIO_Port GPIOB
#define PB15_W_Pin GPIO_PIN_15
#define PB15_W_GPIO_Port GPIOB
#define EXTI6_HALL_U_Pin GPIO_PIN_6
#define EXTI6_HALL_U_GPIO_Port GPIOC
#define EXTI6_HALL_U_EXTI_IRQn EXTI9_5_IRQn
#define EXTI7_HALL_V_Pin GPIO_PIN_7
#define EXTI7_HALL_V_GPIO_Port GPIOC
#define EXTI7_HALL_V_EXTI_IRQn EXTI9_5_IRQn
#define EXTI8_HALL_W_Pin GPIO_PIN_8
#define EXTI8_HALL_W_GPIO_Port GPIOC
#define EXTI8_HALL_W_EXTI_IRQn EXTI9_5_IRQn
#define EXTI9_FAULT_Pin GPIO_PIN_9
#define EXTI9_FAULT_GPIO_Port GPIOC
#define EXTI9_FAULT_EXTI_IRQn EXTI9_5_IRQn
#define TIM1_CH1_U_Pin GPIO_PIN_8
#define TIM1_CH1_U_GPIO_Port GPIOA
#define TIM1_CH2_V_Pin GPIO_PIN_9
#define TIM1_CH2_V_GPIO_Port GPIOA
#define TIM1_CH3_W_Pin GPIO_PIN_10
#define TIM1_CH3_W_GPIO_Port GPIOA
#define PC10_DI_LIGHT_Pin GPIO_PIN_10
#define PC10_DI_LIGHT_GPIO_Port GPIOC
#define PC11_DI_BLINKER_L_Pin GPIO_PIN_11
#define PC11_DI_BLINKER_L_GPIO_Port GPIOC
#define PC12_DI_BLINKER_R_Pin GPIO_PIN_12
#define PC12_DI_BLINKER_R_GPIO_Port GPIOC
#define PB3_DO_LIGHT_Pin GPIO_PIN_3
#define PB3_DO_LIGHT_GPIO_Port GPIOB
#define PB5_DO_DC_ON_Pin GPIO_PIN_5
#define PB5_DO_DC_ON_GPIO_Port GPIOB
#define PB8_DO_FAN_Pin GPIO_PIN_8
#define PB8_DO_FAN_GPIO_Port GPIOB
#define READY 0
#define DRIVE 1
#define BREAK 2
#define SWFAULT 3
#define HWFAULT 4
#define DEBUGST 6
#define THROTTLE_THRESHOLD 30 //Threshold for initial start to prevent adc drift
#define MAXDUTY 60		//Motor PWM Duty Cycle
#define MINDUTY 0		//Motor PWM Duty Cycle
#define MAXADC 3170		//throttle MAX 2,55V
#define MINADC 1055		//throttle MIN 0.85V
#define MAXRPM 4500		//Max RPM of the given motor
#define MINRPM 25		//Min RPM of the given motor
#define SW_OC 		 22		//Over Current 			20,5A	((20,5*0,004)/20) /12bitADC
#define SW_UV 		 45		//Under Voltage 		43,5V	((43,5/(39000+2200))*2200) /12bitADC
#define SW_OV 		 60		//Over Voltage 			43,5V
#define SW_OT 		 100	//Over Temperature 	95°C	((3,3/(10000+1140))*10000)) /12bitADC
#define Temp_FAN_ON  80	//Turn on fan here	75°C
#define Temp_FAN_OFF 60	//Turn off fan here 50°C
#define BLINKER_START 250 // Run blinker at nom. PWM
#define BLINKER_STOP 500  // Turns off blinker PWM
#define ADC_TIMEOUT 20
#define SWFAULT_TIMOUT 300

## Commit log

2024-12-31 STL files für Gehäuse Druck
    [Deckel.stl, Front.stl, Heck.stl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]
2025-01-18 Added stage messaging
2025-01-18 fixxed bug on debug state added output clear on startup, shorter start up
    [main.c]
2025-01-19 Add files via upload
    LCD STL Files
    [LCD_CASE_Bottom.stl, LCD_CASE_TOP.stl]
2025-01-19 Add files via upload
    Motor Test stand STLs
    [Flansch L.stl, Flansch R.stl, Foot L.stl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]
2025-01-25 added State of charge function Merge branch 'main' of https://github.com/leonreeh/E-Bike-ECU.git into main
2025-01-27 Added ADC filter

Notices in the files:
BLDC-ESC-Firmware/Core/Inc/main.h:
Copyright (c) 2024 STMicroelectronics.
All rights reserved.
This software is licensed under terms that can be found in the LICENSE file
